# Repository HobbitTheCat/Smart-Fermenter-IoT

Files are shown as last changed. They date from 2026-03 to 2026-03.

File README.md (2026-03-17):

# Smart Fermentation IoT

A broken yogurt maker became an opportunity to build a complete embedded control system — combining real-time temperature regulation, a finite state machine UI, and remote control over Wi-Fi.

<table>
  <tr>
    <td align="center" width="50%">
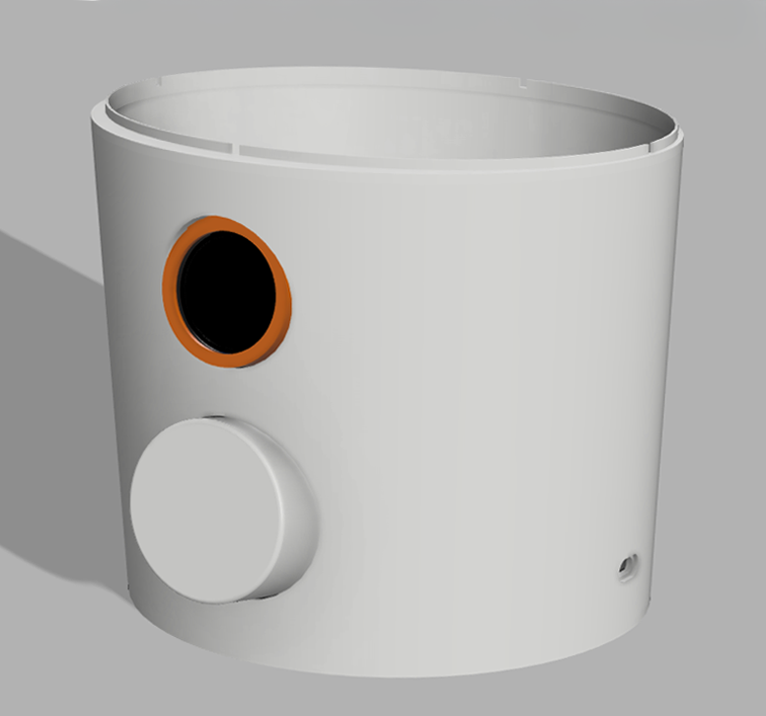
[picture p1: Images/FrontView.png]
      <br>
      <b>CAD Model (Fusion 360)</b>
    </td>
    <td align="center" width="50%">
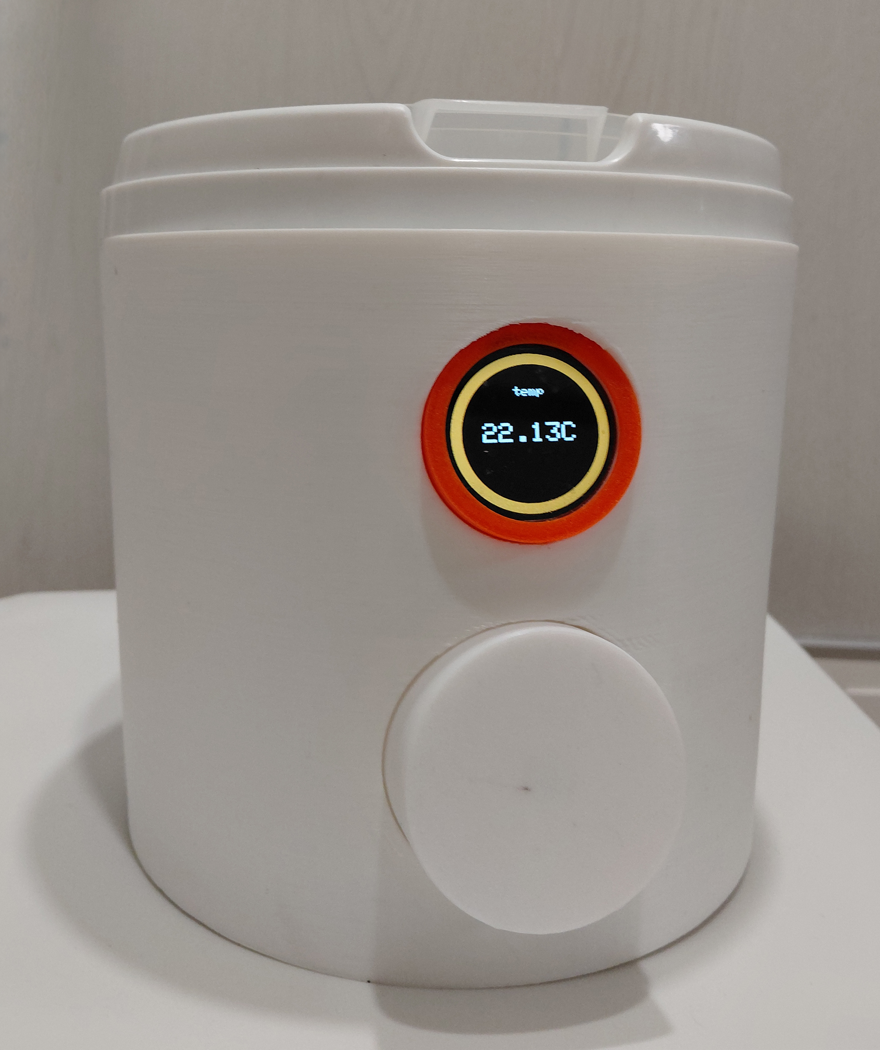
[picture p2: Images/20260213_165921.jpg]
      <br>
      <b>Final Build</b>
    </td>
  </tr>
</table>

The enclosure and PCB were designed before assembly, resulting in a close match between the digital model and the physical device.

---

## Overview
This project is not just a household appliance, but a small embedded system combining:
- Real-time control (temperature regulation)
- Human-machine interface (FSM-driven UI)
- Network communication (Wi-Fi + HTTP API)

---

## Features

- Closed-loop temperature control (hysteresis-based)
- FSM-driven user interface (encoder + button)
- Adjustable temperature and timer (editable during operation)
- Web interface for remote control
- Smart Home integration via Wi-Fi
- Temperature logging via serial output

---

## Architecture

The firmware is structured as a finite state machine (FSM), where each state encapsulates its own behavior and input handling.

Instead of a monolithic `switch-case` , each state is implemented as a class inheriting from a common `State` interface:

```C++
class State {
protected:
    FSM* fsm;

public:
    virtual void onShortPress() {};
    virtual void onLongPress() {};
    virtual void onRotate(int dir) {};
    virtual void running() {};

    virtual StateType getType();
    void setFSM(FSM* fsmPtr) { this->fsm = fsmPtr; }
    virtual ~State() {};
};
```

### Navigation Logic:

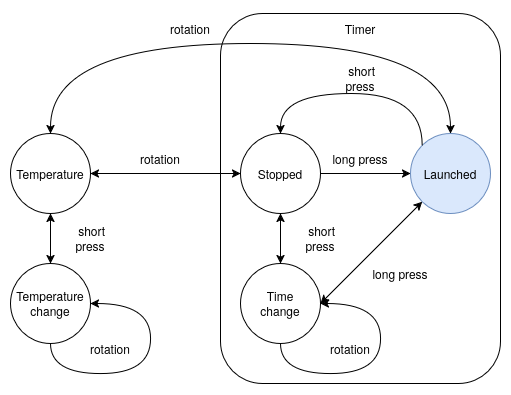
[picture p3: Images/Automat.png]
Navigation liogic


The FSM architecture helped eliminate early logic bugs and makes the system easily extensible.

### Design properties

- Each state defines its own reactions to input events
- No global branching logic
- Easy extensibility: adding a state = adding a class
- Clear separation between UI behavior and control logic

### Example: Running state

```C++
void RunningState::onShortPress() {
    this->fsm->timer.pause();
    this->fsm->changeState(new IdleState());
}

void RunningState::onLongPress() {
    this->fsm->changeState(new TimeEditingState());
}

void RunningState::onRotate(int dir) {
    this->fsm->changeState(new TemperatureState());
}
``` 

The main loop delegates execution to the active state, which updates only the necessary parts of the UI.

---

## Temerature Control
Temperature is controlled using hysteresis switching instead of PID.

### Reasoning
- PID with relay control requires frequent switching → reduces relay lifespan
- Thermal inertia of the system reduces the need for tight control
- Full-power heating decreases time to reach target temperature

### Parameters

- Hysteresis band: ±0.25°C
- Sampling: periodic (main loop)
- No filtering applied

### Observed behavior

- Ramp-up overshoot: up to +4°C
- Steady-state accuracy: ±1–1.5°C
- Time to reach target (~42°C): 15–20 minutes (closed lid)

This trade-off favors simplicity and reliability over theoretical precision.

---

## Hardware

| Component | Role |
| --- | --- |
| ESP32 | Main MCU + Wi-Fi |
| DS18B20 | Temperature sensor |
| SSR-40A | Heater control |
| HLK-10M05 | AC/DC power supply |
| Rotary encoder | User input |
| TFT display | UI |

### Design decisions
- **ESP32:** dual-core allows separation of UI and networking
- **SSR relay:** more reliable than mechanical relay (no wear from switching)
- **DS18B20:** simple and sufficient for required accuracy

### Limitations
- No sensor failure detection
- No watchdog / crash recovery
- Overheat protection implemented as simple cutoff

One of the early versions of the electrical diagram:

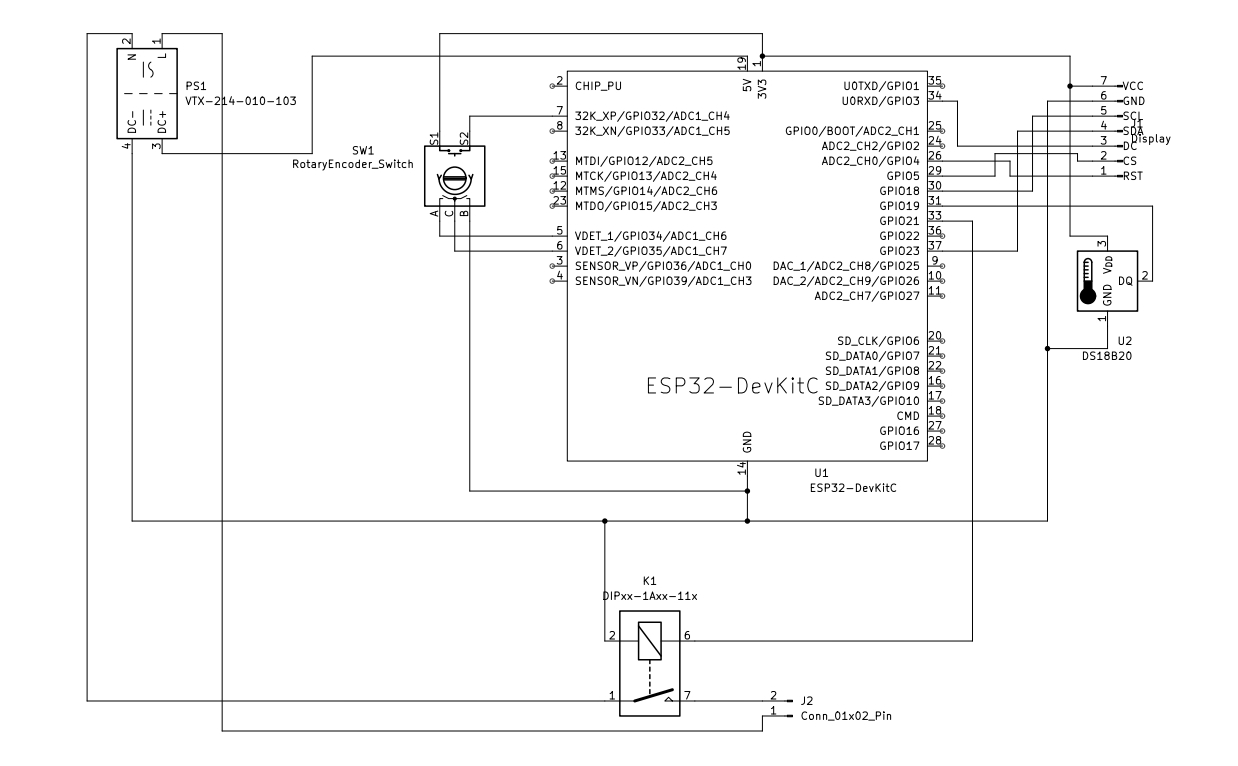
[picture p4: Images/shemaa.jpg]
Early version


---

## Web Interface
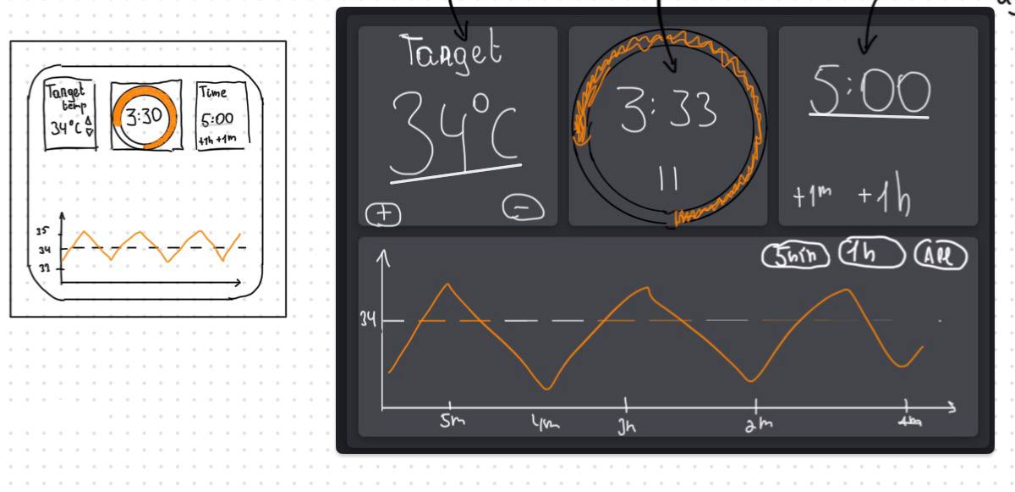
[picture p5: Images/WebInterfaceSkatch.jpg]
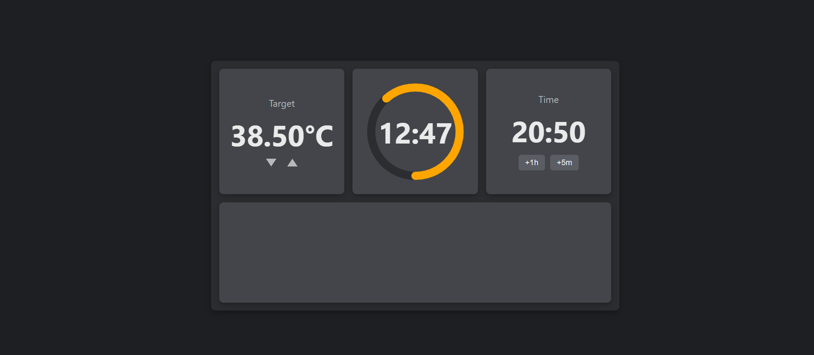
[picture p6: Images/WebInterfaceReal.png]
<table> <tr> <td align="center"><br><b>UI Sketch</b></td> <td align="center"><br><b>Implementation</b></td> </tr> </table>

The ESP32 runs an HTTP server on a separate core.

### API Examples

```C++
POST /api/start
POST /api/pause
POST /api/set_time
```

### Behavior
- Client sends commands via REST-like endpoints
- State changes are immediately applied in firmware
- UI and web interface stay consistent

### Limitations
- No concurrency control (last request wins)
- No multi-client synchronization
- Polling-based updates (no WebSocket)

---

## System Behavior & Measurements
- Temperature logging available via serial output
- Overshoot during heating: ~4°C
- Stable regime: ±1–1.5°C
- Time to reach operating temperature: 15–20 minutes

These measurements confirm that hysteresis control is sufficient for fermentation use.

---

## UI Design Trade-offs
Using a single encoder + button for all interactions led to a complex and unintuitive interface.

### Observable issues
- Navigation and confirmation share the same input
- User flow becomes difficult to predict

Separating input roles is necessary.
In future it may be interesting to add a second dedicated button.

---

## Implementation Details
- UI optimized to update only changed elements (low display refresh rate)
- Temperature sensor required thermal coupling (thermal paste) for accuracy
- FSM architecture helped eliminate early logic bugs

---

### Lessons Learned (Post-Mortem)
| Decision | Observation | Future Improvement |
| --- | --- | --- |
| Single Encoder Input | Navigating and confirming with one button was unintuitive. | Add a second dedicated button to separate navigation from confirmation. |
| Volatile Settings | Settings are lost on power cycles. | Store setpoints in ESP32 Non-Volatile Storage (NVS). |
| Error Handling | No sensor failure or crash recovery detection. | Implement a Watchdog timer and sensor health checks.|

---

### Repository Structure

```
├── Firmware/ 			# PlatformIO C++ Project
│   └── src/
│       ├── FSM/
│       ├── main.cpp
│       ├── temperature.h
│       ├── timer.h
│       └── webInterface.h
├── Hardware/ 			# Fusion 360 Models & KiCad Schematics
│   ├── MainAssembly.f3d
│   └── Shema/
├── WebInterface/ 		# HTML, CSS, and JavaScript
└── Images/			# Project documentation assets
```

---

# Stack
- Firmware: C++ (PlatformIO)
- Hardware design: KiCad, Fusion 360
- Web: HTML / CSS / JavaScript
- Connectivity: Wi-Fi (ESP32), HTTP server

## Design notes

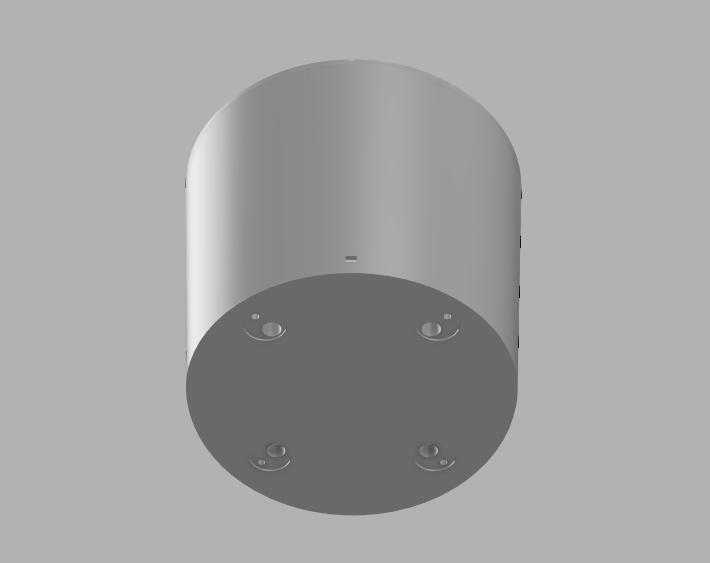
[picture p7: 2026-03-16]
Images/BackView.png

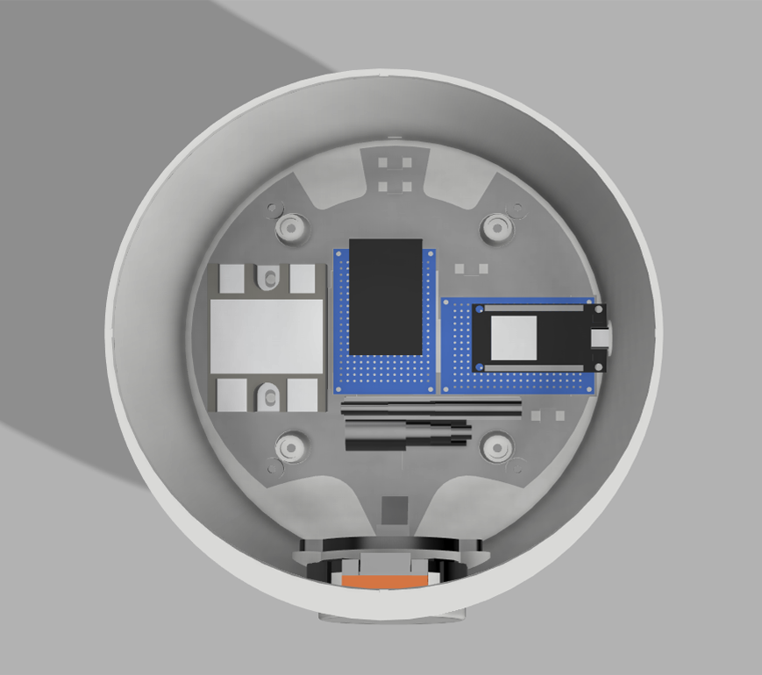
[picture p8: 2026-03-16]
Images/TopView.png

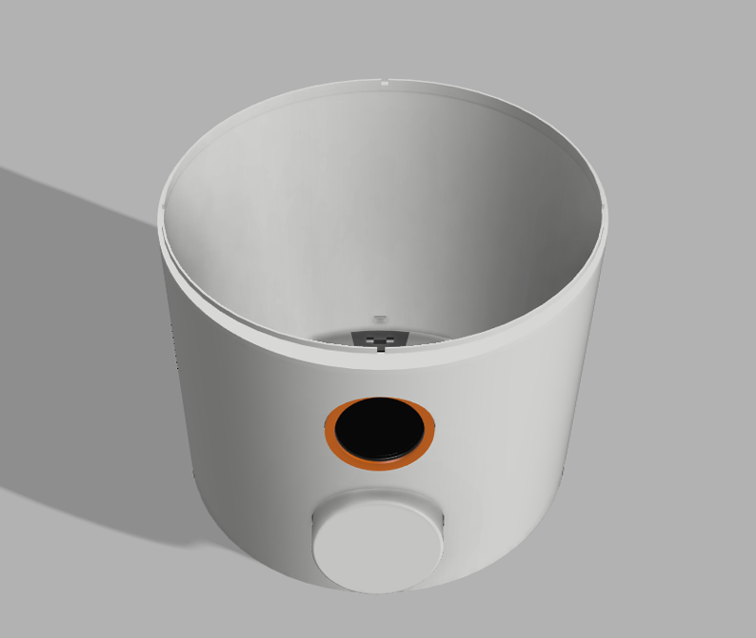
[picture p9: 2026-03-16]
Images/FrontViewV2.png

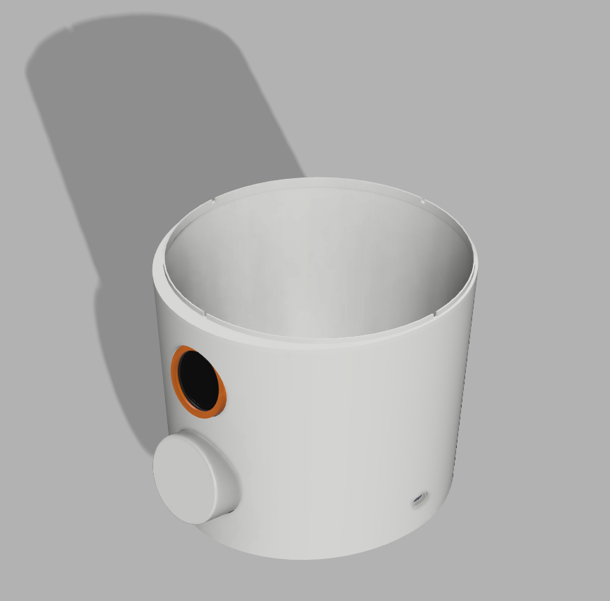
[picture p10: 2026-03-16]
Images/SideView.png

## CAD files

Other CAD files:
Hardware/MainAssembly.f3d

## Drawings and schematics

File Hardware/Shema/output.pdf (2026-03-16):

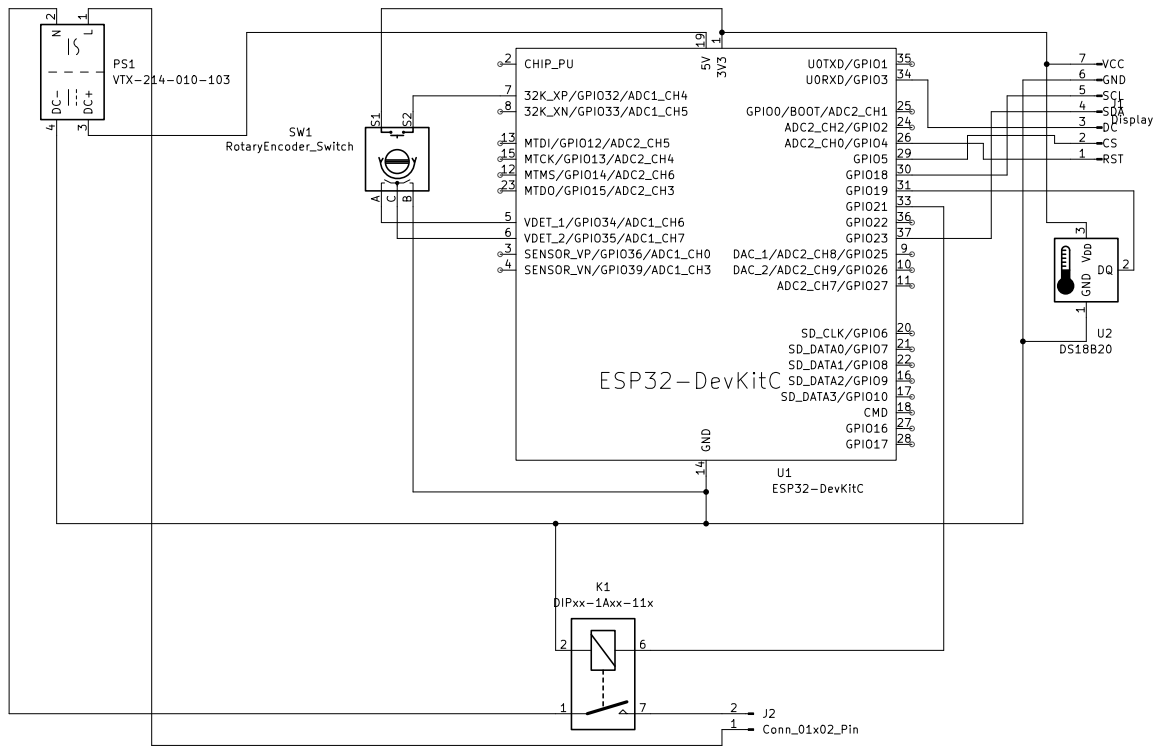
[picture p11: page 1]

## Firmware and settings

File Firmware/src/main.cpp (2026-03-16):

#include <Arduino.h>
#include <OneWire.h>
#include <DallasTemperature.h>
#include "display.h"
#include "utils.h"
#include "encoder.h"
#include "timer.h"
#include "FSM/fsm.h"
#include "FSM/states/h/idleState.h"
#include "tcu.h"
#include "webInterface.h"

TFT_eSPI tft = TFT_eSPI();

Display display(tft, TFT_WHITE, Utils::color(0, 13, 15), Utils::color(253, 157, 46), Utils::color(28, 35, 36));
EncoderReader encoder(34, 35, 32);
Temperature temp(19);
TCU tcu(temp, 21, 10);
Timer timer = Timer(tcu);
FSM fsm(new IdleState(), tft, timer, display, temp, tcu);
WebInterface web(fsm, "SK_WiFiGIGA2E5E_2.4G", "BATCE@2412");

uint32_t lastTimerInfo = 0;

void setup() {
    timer.setRemainningTime(3000000);
    Serial.begin(115200);
    web.begin();
}



void loop() {

    encoder.update();          
    encoder.updateEncoder();

    timer.update();
    temp.update();
    tcu.update();

    
    if (encoder.wasShortPressed()) {
        fsm.handleShortPress();
    }    
    if (encoder.wasLongPressed()) {
        fsm.handleLongPress();
    }
    if (encoder.hasChanged()) {
        fsm.handleRotate(encoder.getDirection());
    }

    fsm.running();
}

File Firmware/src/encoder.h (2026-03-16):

#ifndef ENCODERREADER_H
#define ENCODERREADER_H

#include <Arduino.h>

class EncoderReader {
private:
    const unsigned long LONG_PRESS_TIME = 800; // мс
    const unsigned long ENCODER_UPDATE_INTERVAL = 5;

    int _pinA, _pinB, _pinBtn;
    unsigned long _lastEncoderPoll = 0;
    int _encoderPos = 0;
    int _lastState = 0;
    int _lastReported = 0;
    int _direction = 0;

    int _buttonState = HIGH;
    int _lastButtonState = HIGH;
    unsigned long _buttonPressedTime = 0;
    bool _shortPressDetected = false;
    bool _longPressDetected = false;
    bool _longPressReported = false;

    uint32_t lastUnpress = 0;

public:
    EncoderReader(int pinA, int pinB, int pinBtn)
        : _pinA(pinA), _pinB(pinB), _pinBtn(pinBtn) {
        pinMode(_pinA, INPUT);
        pinMode(_pinB, INPUT);
        pinMode(_pinBtn, INPUT_PULLUP);

        _lastState = (digitalRead(_pinA) << 1) | digitalRead(_pinB);
    }

    void update() {
        int reading = digitalRead(_pinBtn);
        uint32_t now = millis();

        if (_lastButtonState == HIGH && reading == LOW) {
            if (now - this->lastUnpress > 100) {
                _buttonPressedTime = now;
                _longPressReported = false;
            } else {
            }
        }
        else if (reading == LOW && !_longPressReported && now - _buttonPressedTime >= LONG_PRESS_TIME) {
            _longPressDetected = true;
            _longPressReported = true;
        }
        else if (_lastButtonState == LOW && reading == HIGH) {
            if (!_longPressReported && now - _buttonPressedTime < LONG_PRESS_TIME) {
                _shortPressDetected = true;
            }
            _buttonPressedTime = 0;
            this->lastUnpress = now;
        }

        _lastButtonState = reading;
    }


    void updateEncoder() {
        unsigned long now = millis();
        if (now - _lastEncoderPoll < ENCODER_UPDATE_INTERVAL) return;
        // Serial.printf("%d\n", now-_lastEncoderPoll);
        _lastEncoderPoll = now;

        int a = digitalRead(_pinA);
        int b = digitalRead(_pinB);
        int state = (a << 1) | b;

        int transition = (_lastState << 2) | state;

        switch (transition) {
            case 0b0001:
            case 0b0111:
            case 0b1110:
            case 0b1000:
                _encoderPos++;
                _direction = 1;
                break;
            case 0b0010:
            case 0b1011:
            case 0b1101:
            case 0b0100:
                _encoderPos--;
                _direction = -1;
                break;
        }

        _lastState = state;
    }

    int getPosition() {
        return _encoderPos / 4;
    }

    bool hasChanged() {
        int current = getPosition();
        if (current != _lastReported) {
            _lastReported = current;
            return true;
        }
        return false;
    }

    bool wasShortPressed() {
        if (_shortPressDetected) {
            _shortPressDetected = false;
            return true;
        }
        return false;
    }

    bool wasLongPressed() {
        if (_longPressDetected) {
            _longPressDetected = false;
            return true;
        }
        return false;
    }

    int getDirection() {
        int dir = _direction;
        _direction = 0;
        return dir;
    }
};

#endif
